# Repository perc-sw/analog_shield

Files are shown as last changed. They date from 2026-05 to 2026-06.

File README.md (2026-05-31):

# Analog Shield

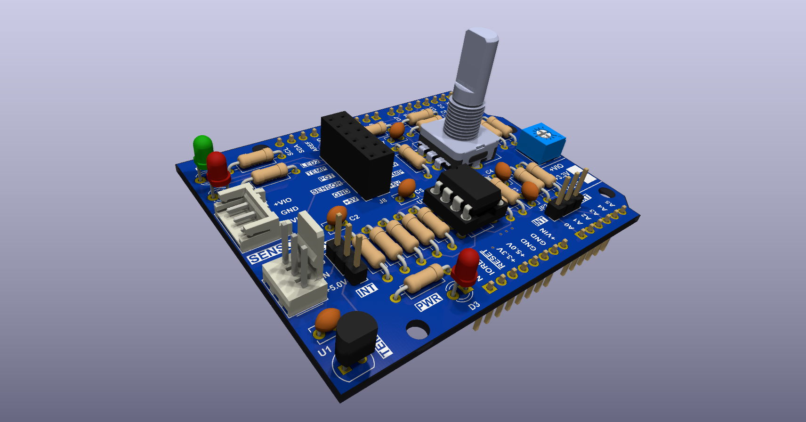
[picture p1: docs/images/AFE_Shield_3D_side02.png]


## Description

This repository has all CAD files for the Analog Shield board used in the University of Toronto, Department of Physic, "[Introduction to Electronics](https://plrs.physics.utoronto.ca/course-listing/) course." 

This board is used to train graduate students first and foremost in through hole solder techniques. As part of the training in the course they will as learn analog front end, digital IO design methods as well. Other than a teaching aid there is not intended practical use for this board.

The CAD program used to design this board is [KiCAD](https://www.kicad.org/) which open source and free to use. The [Interactive Html BoM](https://github.com/openscopeproject/InteractiveHtmlBom) plugin was used to generate the interactive bill of materials html file.

## Files

- Gerber Files are located in the [fabrication folder](./fabrication/)
- There is an [Interactive bill of materials html file](https://perc-sw.github.io/analog_shield/bom/ibom.html) that you can use to assist you in assembling the board. 
- PDF of [Schematic](./docs/pdf/board/analog_sheild_schematic.pdf)
- PDF of PCB
    - [Top layer Cu](./docs/pdf/board/analog_sheild_pcb_top.pdf)
    - [Inner 1 Cu](./docs/pdf/board/analog_sheild_pcb_inner_1.pdf)
    - [Inner 2 Cu](./docs/pdf/board/analog_sheild_pcb_inner_2.pdf)
    - [Bottom layer Cu](./docs/pdf/board/analog_sheild_pcb_bottom.pdf)

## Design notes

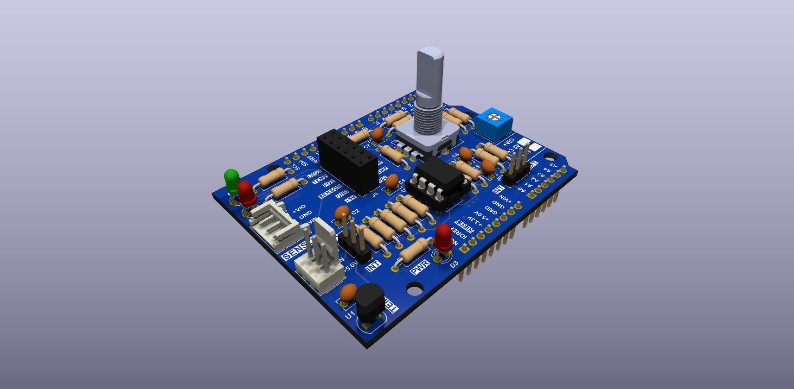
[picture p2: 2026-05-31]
docs/images/AFE_Shield_3D_side01.png

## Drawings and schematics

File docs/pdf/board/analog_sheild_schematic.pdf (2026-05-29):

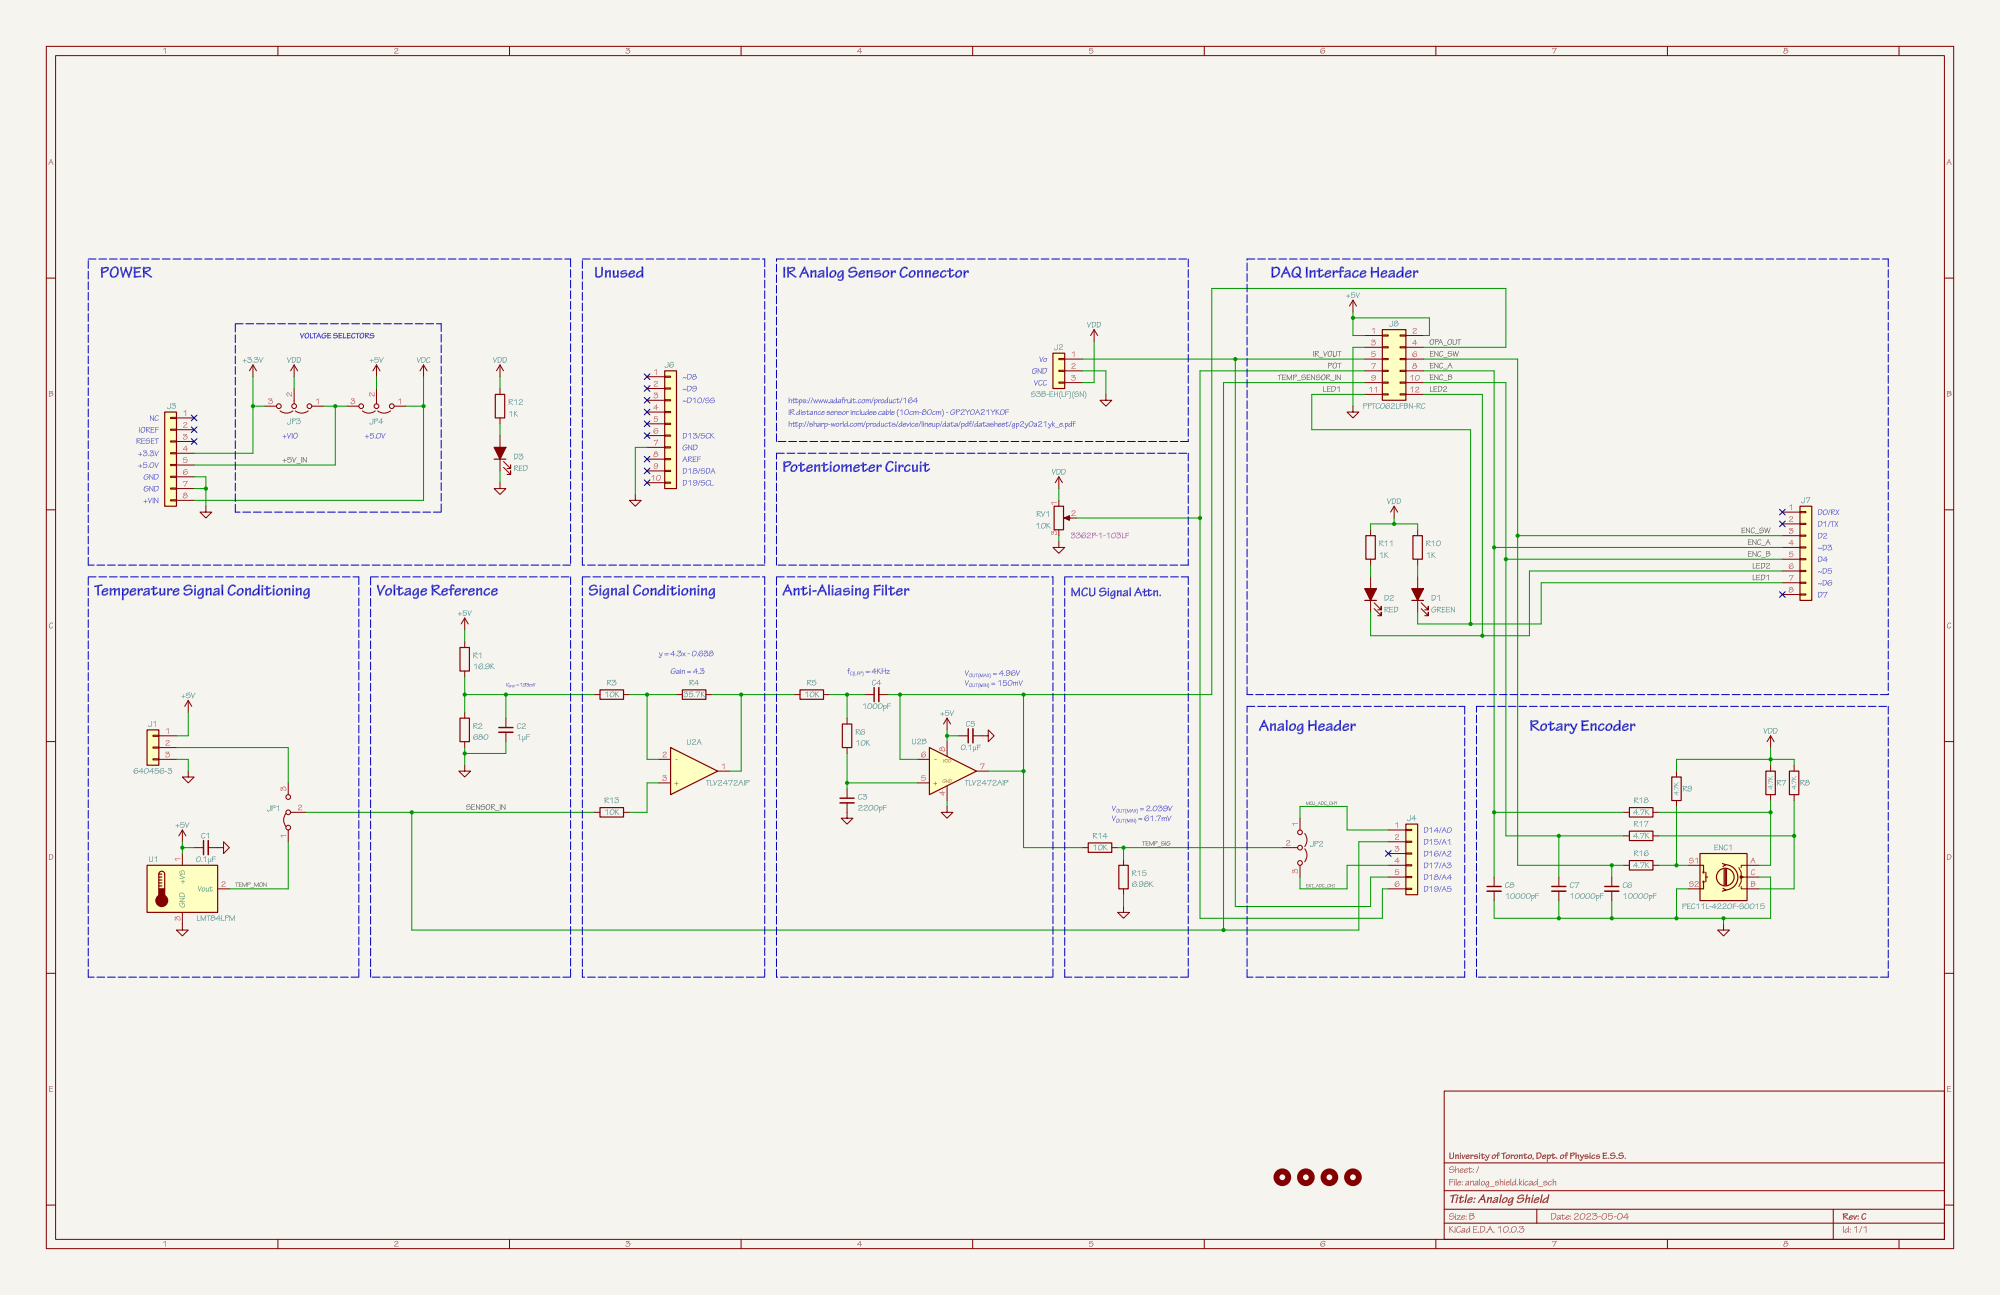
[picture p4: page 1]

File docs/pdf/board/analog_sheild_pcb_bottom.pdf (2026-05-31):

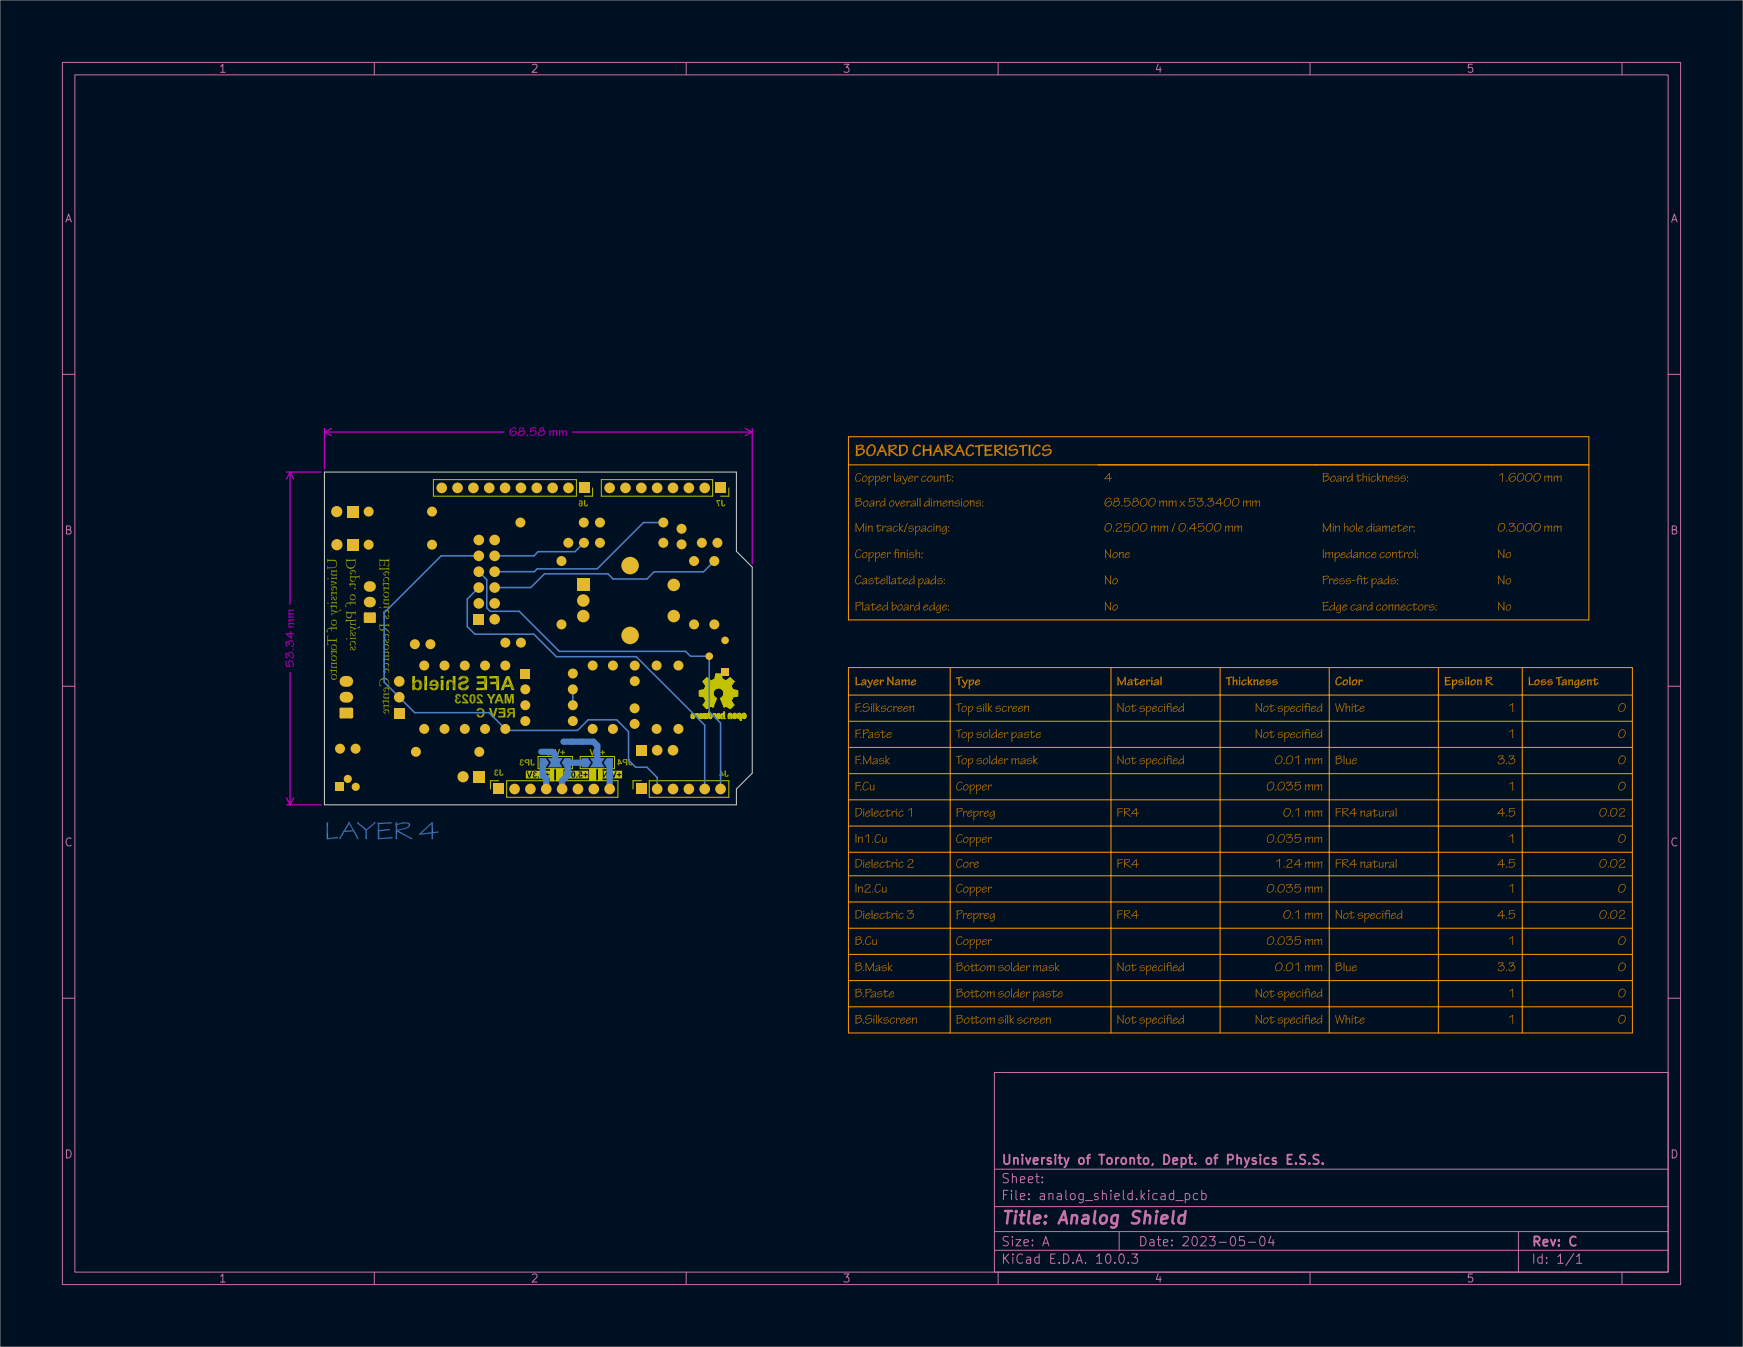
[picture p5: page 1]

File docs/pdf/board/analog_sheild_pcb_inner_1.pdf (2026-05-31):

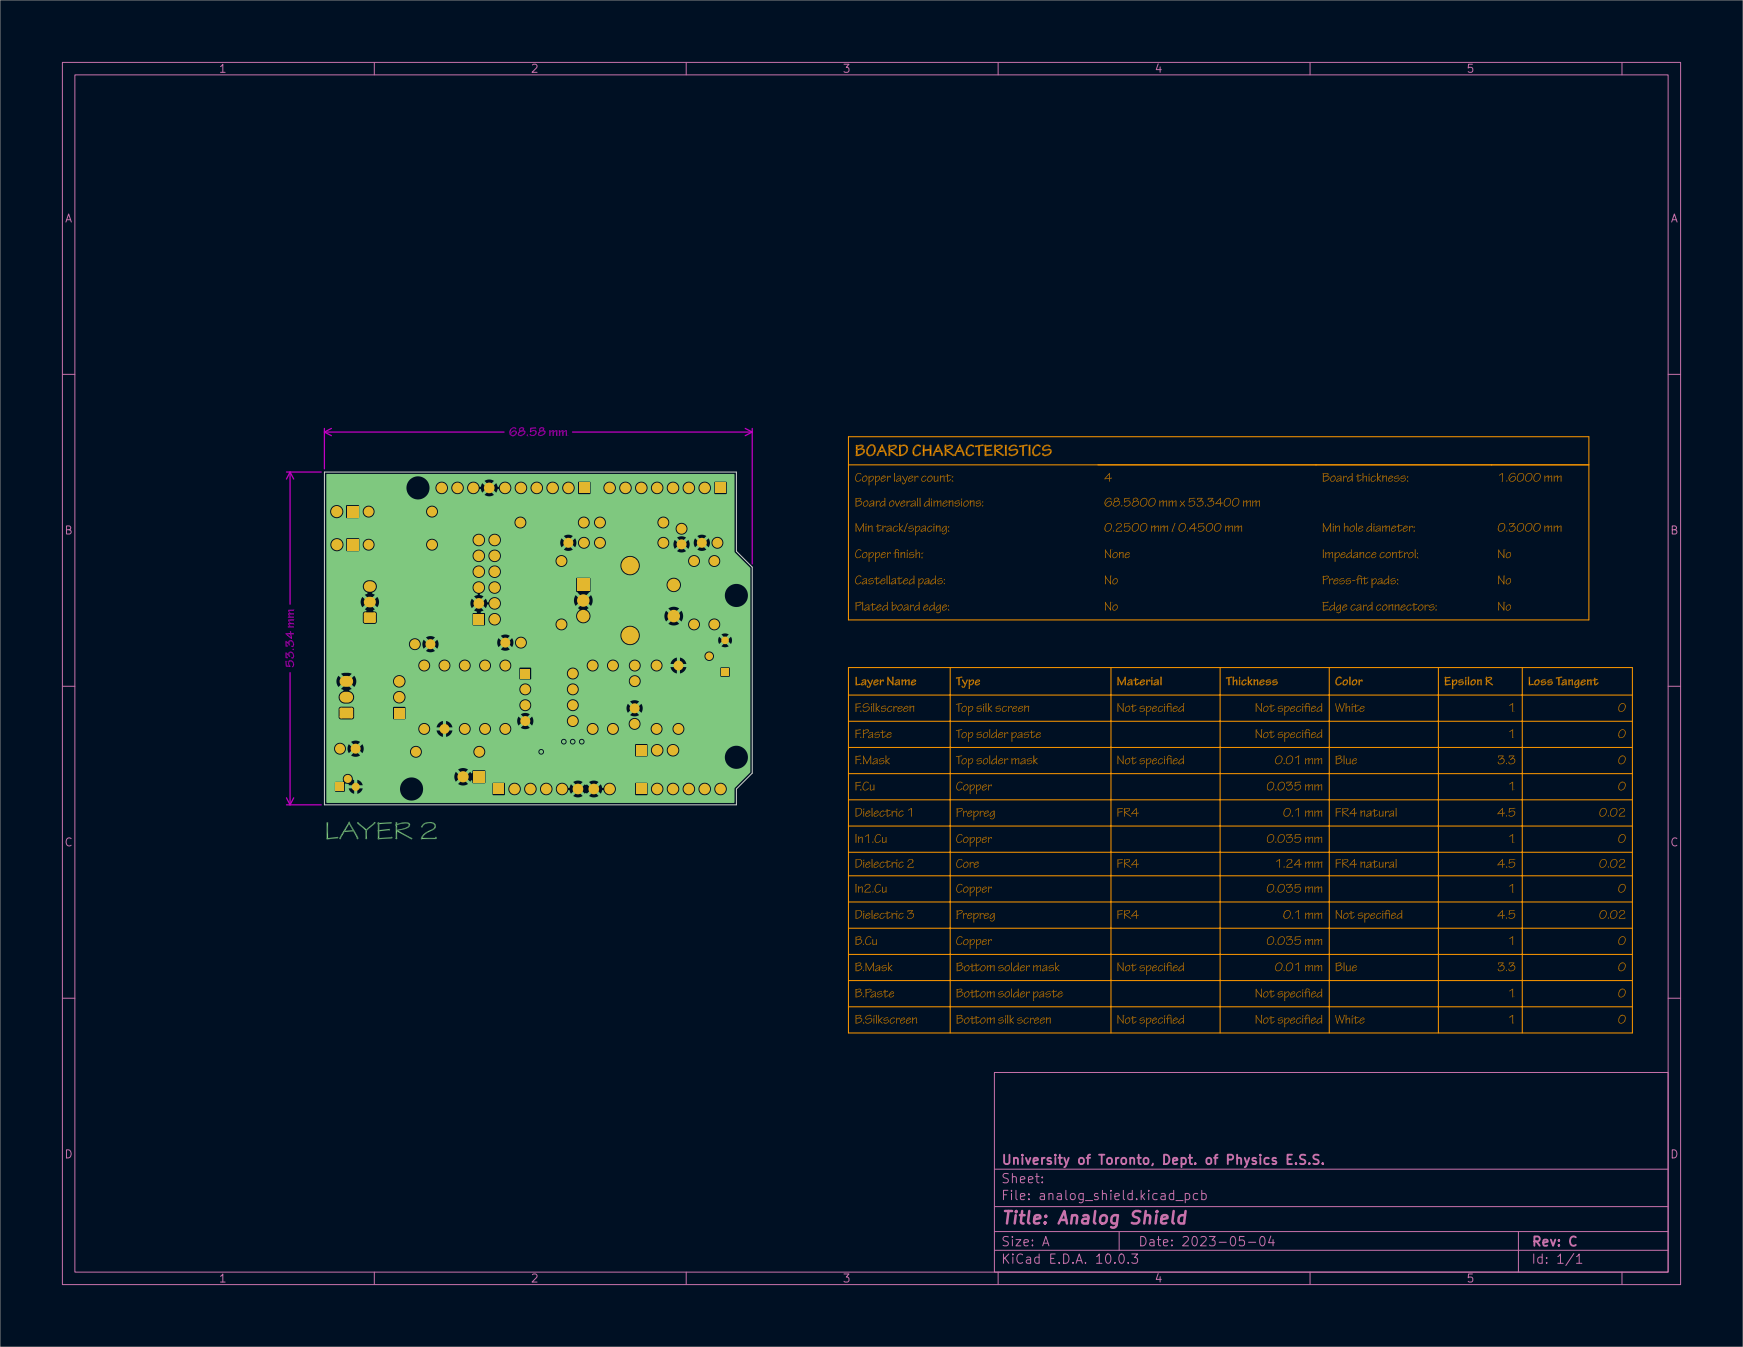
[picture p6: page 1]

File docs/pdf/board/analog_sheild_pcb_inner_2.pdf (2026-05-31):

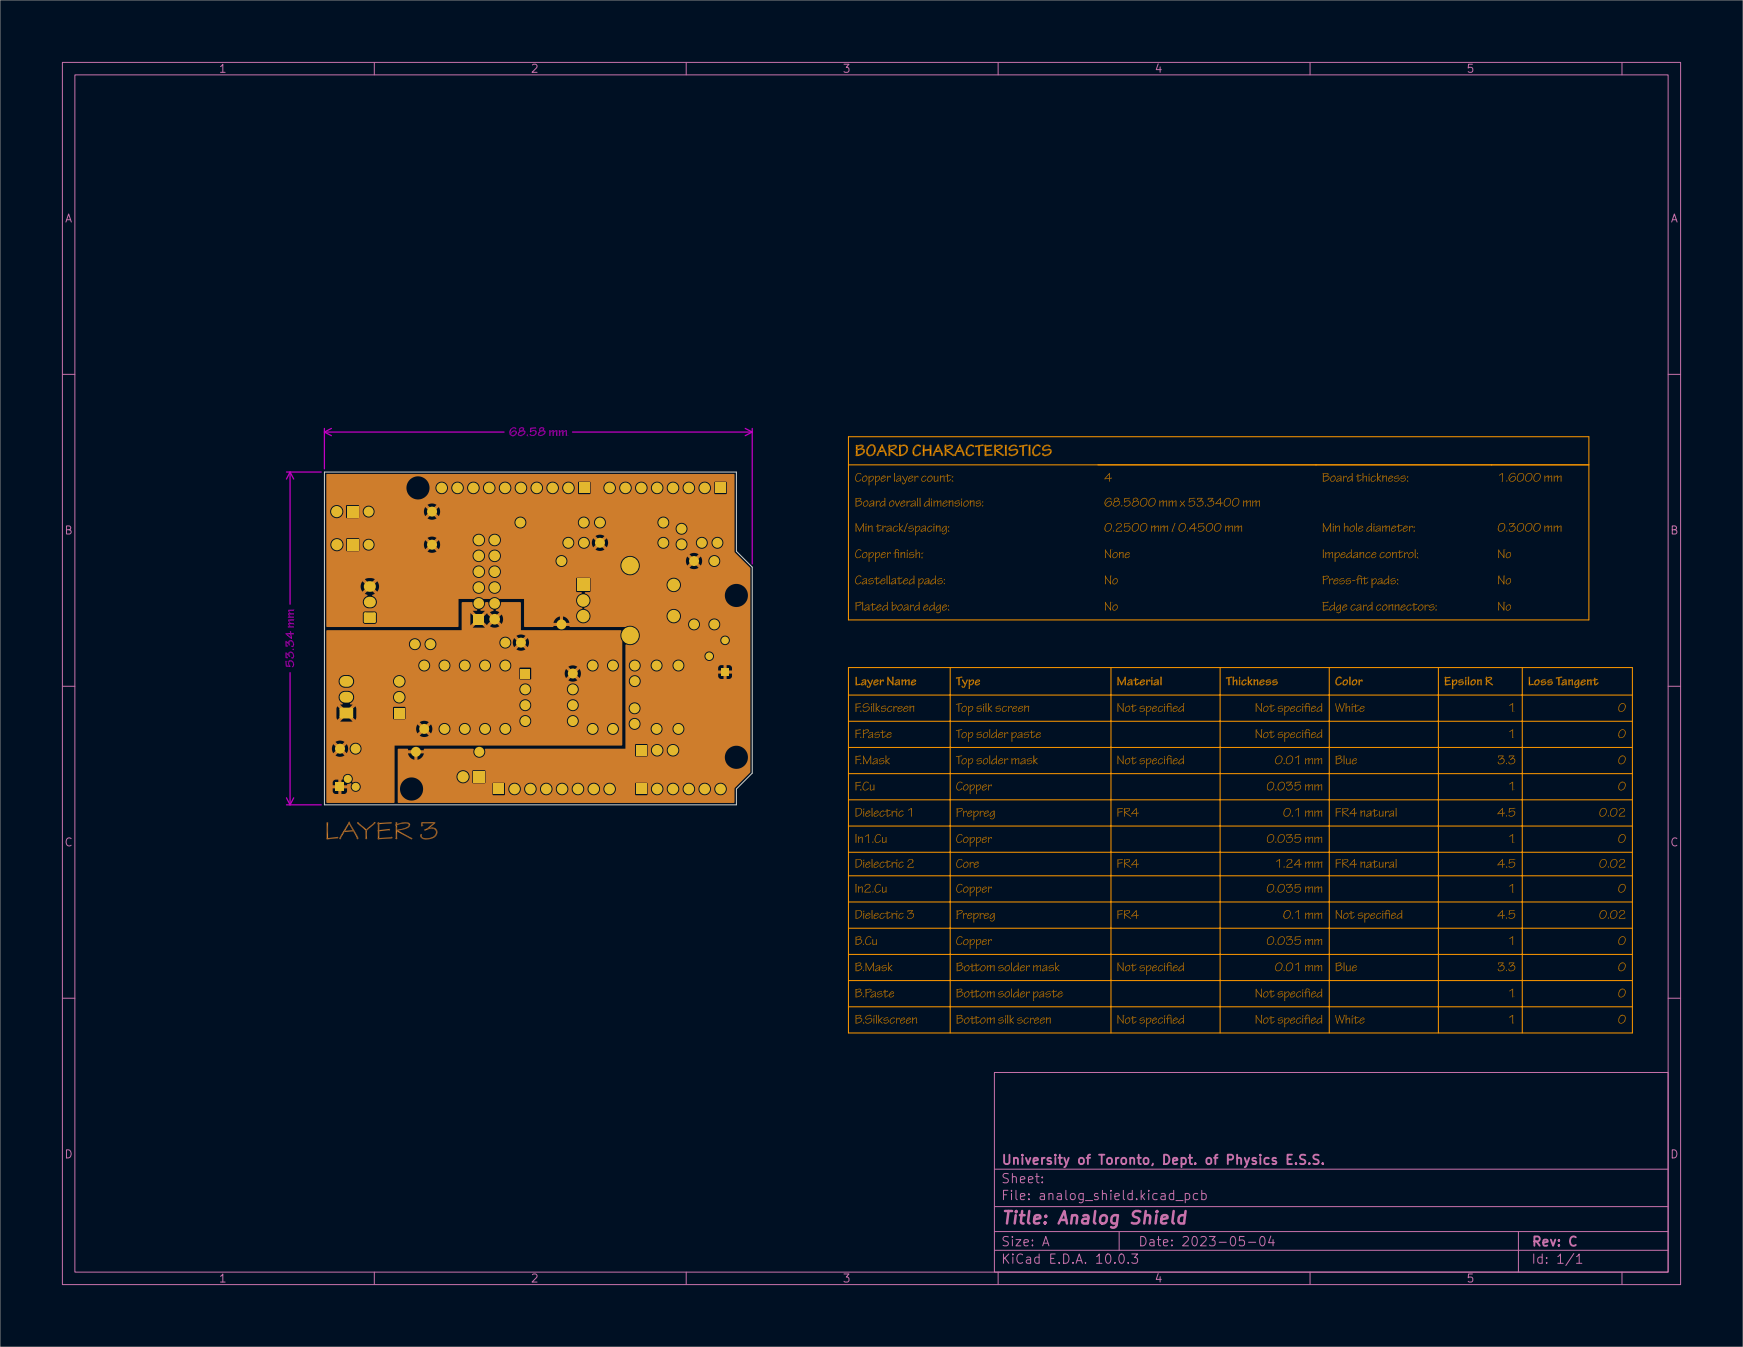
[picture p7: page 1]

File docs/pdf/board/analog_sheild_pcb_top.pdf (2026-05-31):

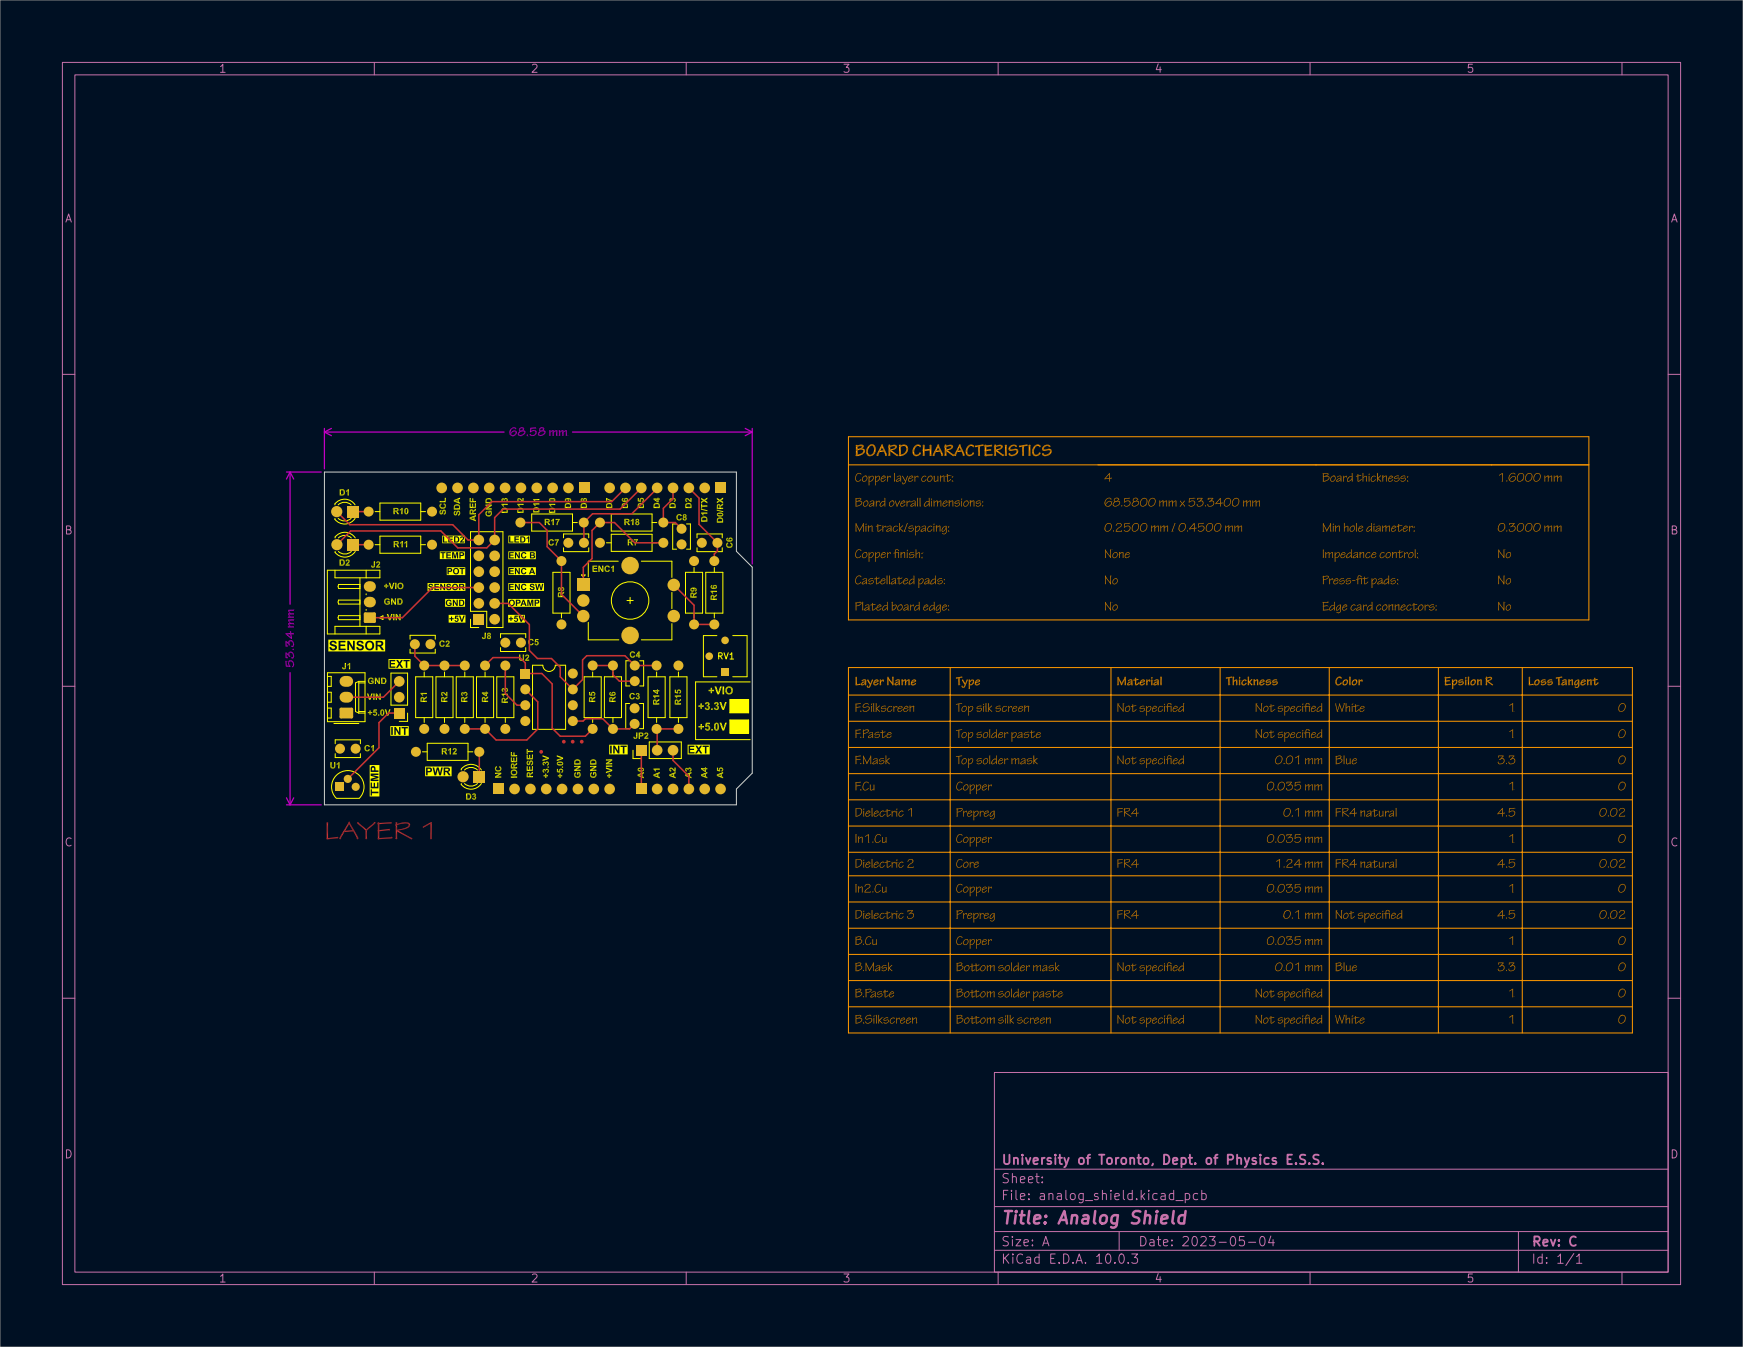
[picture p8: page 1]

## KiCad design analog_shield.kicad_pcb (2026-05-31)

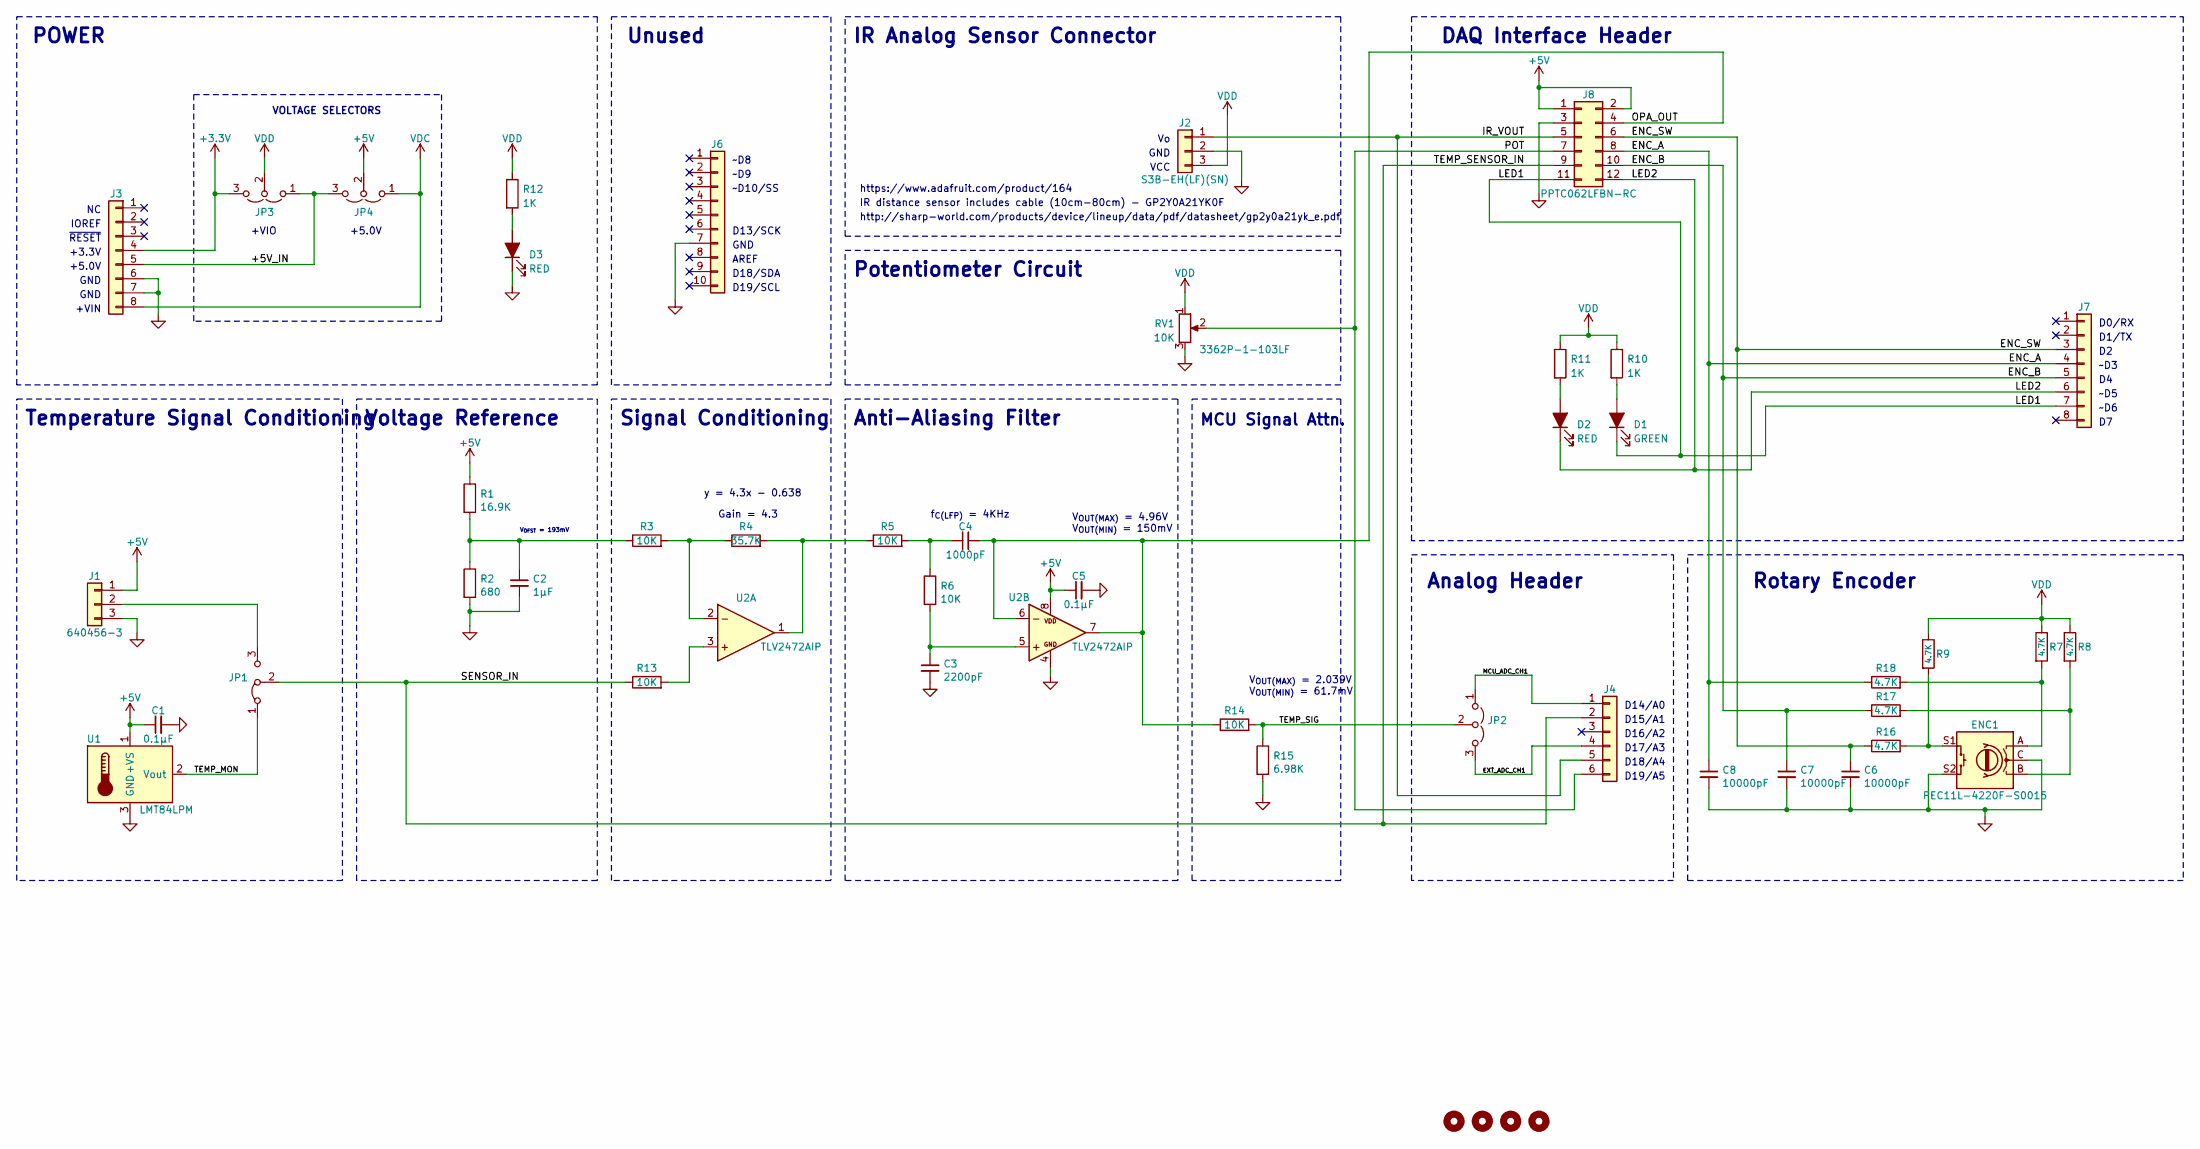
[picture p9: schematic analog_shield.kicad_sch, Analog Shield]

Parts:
C1, C5: 0.1µF; C_Disc_D3.8mm_W2.6mm_P2.50mm
C2: 1µF; C_Disc_D3.8mm_W2.6mm_P2.50mm
C3: 2200pF; C_Disc_D3.8mm_W2.6mm_P2.50mm
C4: 1000pF; C_Disc_D3.8mm_W2.6mm_P2.50mm
C6, C7, C8: 10000pF; C_Disc_D3.8mm_W2.6mm_P2.50mm
D1: GREEN; LED_D3.0mm
D2, D3: RED; LED_D3.0mm
ENC1: PEC11L-4220F-S0015; RotaryEncoder_Alps_EC12E-Switch_Vertical_H20mm_CircularMoun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
H1, H2, H3, H4: MountingHole; MountingHole_3.2mm_M3
J1: 640456-3; Molex_KK-254_AE-6410-03A_1x03_P2.54mm_Vertical
J2: S3B-EH(LF)(SN); JST_EH_S3B-EH_1x03_P2.50mm_Horizontal
J3, J7: Conn_01x08; PinHeader_1x08_P2.54mm_Vertical
J4: Conn_01x06; PinHeader_1x06_P2.54mm_Vertical
J6: Conn_01x10; PinHeader_1x10_P2.54mm_Vertical
J8: PPTC062LFBN-RC; PinSocket_2x06_P2.54mm_Vertical
JP1: Jumper_3_Bridged12; PinHeader_1x03_P2.54mm_Vertical
JP2: Jumper_3_Open; PinHeader_1x03_P2.54mm_Vertical
JP3, JP4: Jumper_3_Open; SolderJumper-3_P2.0mm_Open_TrianglePad1.0x1.5mm
R1: 16.9K; R_Axial_DIN0207_L6.3mm_D2.5mm_P10.16mm_Horizontal
R2: 680; R_Axial_DIN0207_L6.3mm_D2.5mm_P10.16mm_Horizontal
R3, R5, R6, R13, R14: 10K; R_Axial_DIN0207_L6.3mm_D2.5mm_P10.16mm_Horizontal
R4: 35.7K; R_Axial_DIN0207_L6.3mm_D2.5mm_P10.16mm_Horizontal
R7, R8, R9, R16, R17, R18: 4.7K; R_Axial_DIN0207_L6.3mm_D2.5mm_P10.16mm_Horizontal
R10, R11, R12: 1K; R_Axial_DIN0207_L6.3mm_D2.5mm_P10.16mm_Horizontal
R15: 6.98K; R_Axial_DIN0207_L6.3mm_D2.5mm_P10.16mm_Horizontal
RV1: 10K; TRIM_3362P-1-103LF
U1: LMT84LPM; TO-92
U2: TLV2472AIP; DIP-8_W7.62mm

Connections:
+3.3V: J3.4, JP3.3 (B)
+5V: C1.1, C5.1, J1.1, J8.1, J8.2, JP4.2 (C), R1.1, U1.1 (+VS), U2.8 (V+)
/+5V_IN: J3.5, JP3.1 (A), JP4.3 (B)
/ENC_A: C8.1, J7.4, J8.8, R18.1
/ENC_B: C7.1, J7.5, J8.10, R17.1
/ENC_SW: C6.1, J7.3, J8.6, R16.1
/EXT_ADC_CH1: J4.4, JP2.3 (B)
/IR_VOUT: J2.1, J4.5, J8.5
/LED1: D1.1 (K), J7.7, J8.11
/LED2: D2.1 (K), J7.6, J8.12
/MCU_ADC_CH1: J4.1, JP2.1 (A)
/OPA_OUT: C4.2, J8.4, R14.1, U2.6 (-), U2.7 (OUT)
/POT: J4.6, J8.7, RV1.2
/SENSOR_IN: J4.2, J8.9, JP1.2 (C), R13.1
/TEMP_MON: JP1.1 (A), U1.2 (Vout)
/TEMP_SIG: JP2.2 (C), R14.2, R15.1
GND: C1.2, C2.2, C3.2, C5.2, C6.2, C7.2, C8.2, D3.1 (K), ENC1.C, ENC1.S2, J1.3, J2.2, J3.6, J3.7, J6.7 (Pin_7_7), J8.3, R2.2, R15.2, RV1.3, U1.3 (GND), U2.4 (GND)
unnamed: C2.1, R1.2, R2.1, R3.1
unnamed: C4.1, R5.2, R6.1
unnamed: D1.2 (A), R10.2
unnamed: D2.2 (A), R11.2
unnamed: D3.2 (A), R12.2
unnamed: ENC1.A, R7.2, R18.2
unnamed: ENC1.B, R8.2, R17.2
unnamed: ENC1.S1, R9.2, R16.2
unnamed: J1.2, JP1.3 (B)
unnamed: R13.2, U2.3 (+)
unnamed: R3.2, R4.1, U2.2 (-)
unnamed: R4.2, R5.1, U2.1 (OUT)
unnamed: C3.1, R6.2, U2.5 (+)
VDC: J3.8, JP4.1 (A)
VDD: J2.3, JP3.2 (C), R7.1, R8.1, R9.1, R10.1, R11.1, R12.1, RV1.1

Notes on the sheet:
Signal Conditioning
~D8
AREF
DAQ Interface Header
Anti-Aliasing Filter
D13/SCK
IOREF
VOLTAGE SELECTORS
V_{OUT(MAX)} = 2.039V V_{OUT(MIN)} = 61.7mV
D14/A0
Voltage Reference
~D10/SS
~D9
D17/A3
+5.0V
https://www.adafruit.com/product/164
GND
D19/A5
~D5
D19/SCL
V_{OFST} = 193mV
Unused
~{RESET}
D18/A4
~D6
http://sharp-world.com/products/device/lineup/data/pdf/datasheet/gp2y0a21yk_e.pdf
D16/A2
Temperature Signal Conditioning
f_{C(LFP)} = 4KHz
D1/TX
+VIN
IR Analog Sensor Connector
D18/SDA
~D3
Rotary Encoder
VCC
MCU Signal Attn.
POWER
IR distance sensor includes cable (10cm-80cm) - GP2Y0A21YK0F
D0/RX

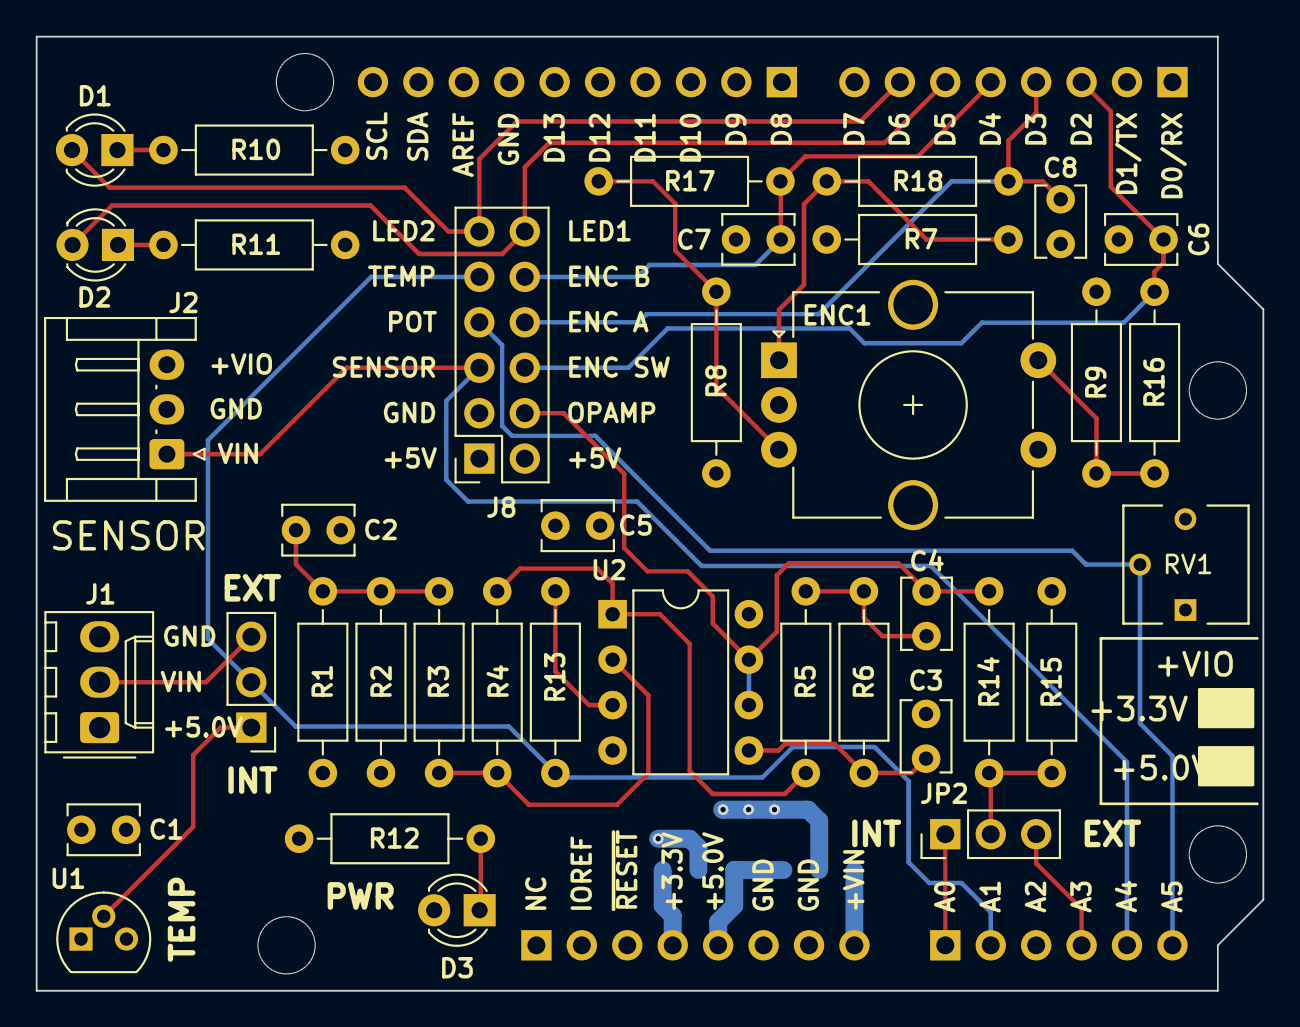
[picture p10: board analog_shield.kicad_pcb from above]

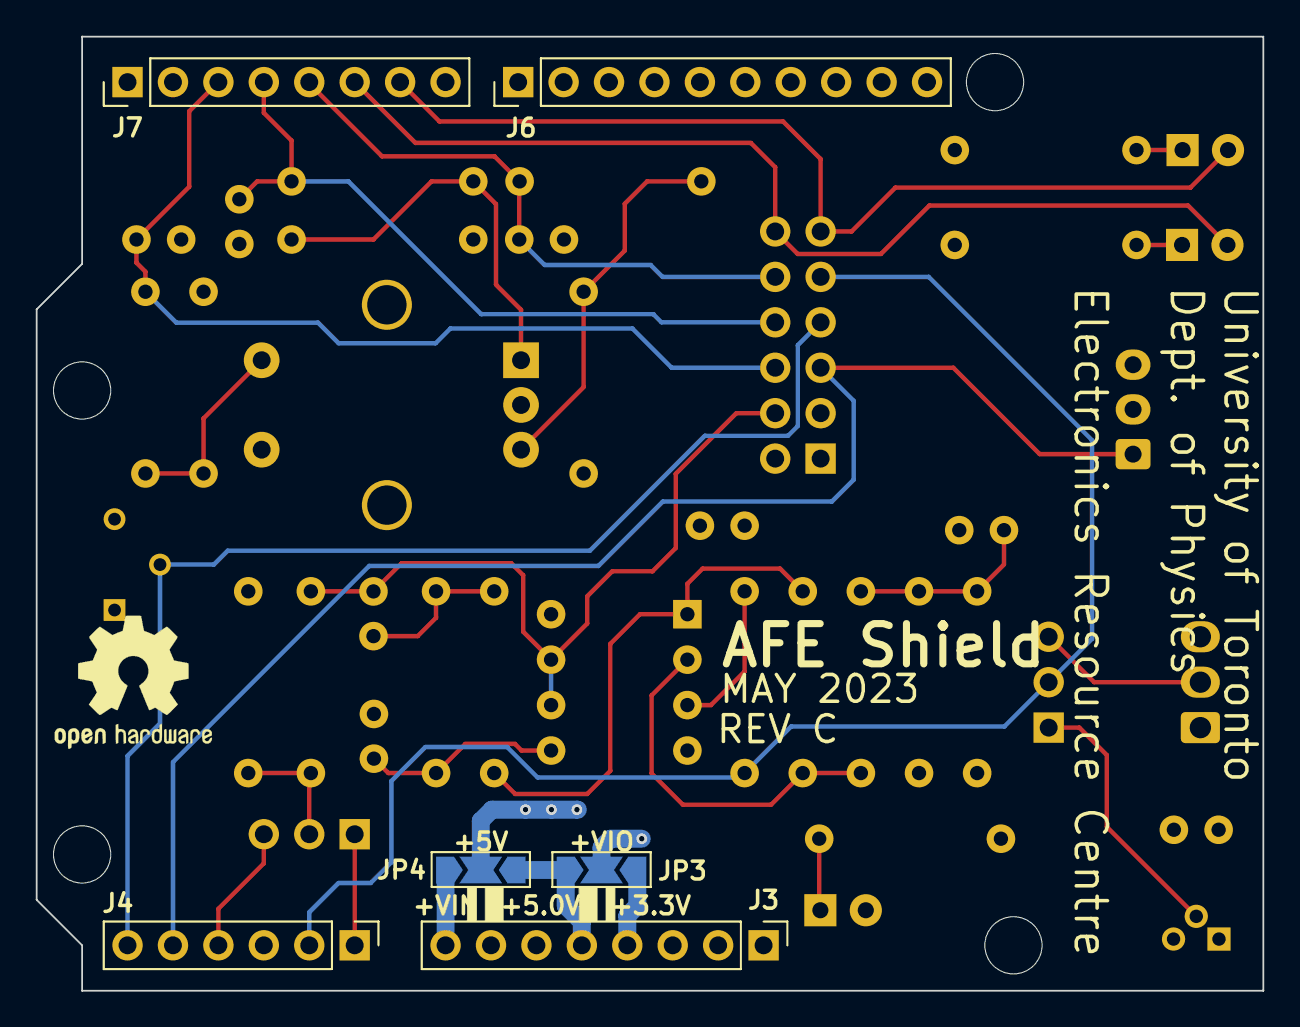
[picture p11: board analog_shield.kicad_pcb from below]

Board: 4 copper layers, 68.6 x 53.3 mm, 48 parts (6 on the bottom side), 32 nets.

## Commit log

2026-05-04 analog shield rev b initial commit
    [analog_shield-B_Cu.gbr, analog_shield-B_Mask.gbr, analog_shield-B_Silkscreen.gbr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]
2026-05-04 Added pdf schematic to repository
2026-05-04 Add pdf of PCB board design
2026-05-29 Updated Title block with correct information, all documentation updated too.
    [analog_shield.kicad_pcb, analog_shield.kicad_sch]
2026-05-31 Documentation and GitHub pages update.
    [analog_shield.kicad_pcb, analog_shield.kicad_sch]
